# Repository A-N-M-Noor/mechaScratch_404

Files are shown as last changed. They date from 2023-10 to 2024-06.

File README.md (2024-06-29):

# wro_fe_2023 Engineering Documentation / PERA-METER / Team mechaScratch_404 / BANGLADESH
----
 <!-- ![mecha scratch main](https://github.com/A-N-M-Noor/mechaScratch_404/assets/136412241/82dec0fd-90a3-4080-8b9e-d6446caba096)   -->
mecha scratch main

### This repository is the collection of engineering materials pertaining to PERA-METER, a self-driving vehicle model developed by Team mechaScratch_404, participating in the 2023 WRO International Final (Future Engineers) from BANGLADESH.
----

## Team Members:
> A. N. M. Noor, email: noornoorrohan15@gmail.com

> Mahir Tajwar Chowdhury - email: tajwar185@gmail.com

----

 <!--  <img align="left" alt="NAUT" width="340" src="https://github.com/A-N-M-Noor/mechaScratch_404/assets/136412241/7f8c3910-39dc-47d4-9438-62cf6487e162">  -->

## Overview of our Repository
NAUT

 * `experiments` - codes that were used to do experiments.  
 * `models` - the 3D printable files used in our robot.
 * `getting started` - getting started guide.
 * `issues and solutions` - Issues we've faced and how we've worked around them.
 * `schematic` - contains the schematic of the electrical system of our robot.
 * `src` - contains the main code of our robot.
 * `video` - contains the video link of YouTube where our robot can be seen in action.
 * `t-photos` - contains one serious and one funny photo of our team.
 * `v-photos` - contains the photos of the robot from all required directions
 * `others` - other essential photos.
----
----
----


## Mechanical Design

We've made our robot totally from scratch. Most of the parts of our robot are 3D printed, starting from chassis, wheels, and so on.

### Mechanical Parts List
* Axial Bearing (8mm x 16mm x 5mm)
* Axial Flange Bearing (3mm x 8mm x 4mm)
* M3 bolt
* M3 nut
* M2 bolt
* M2 nut
* M3 Hex Spacer
* 3d Printed parts
* Zip ties

----

## Robot's Chassis



The chassis of our robot, primarily composed of 3D-printed parts, serves as the robust foundation for all hardware and electronic components. Custom-designed to accommodate our specific needs, each piece has been modeled to interlock seamlessly, providing a lightweight yet durable structure. The modular nature of the 3D-printed chassis allows for easy customization and scalability. It has been engineered to house the motors, electronics, and battery, ensuring proper heat dissipation and weight distribution for optimal performance. This approach not only allows for rapid prototyping and iterative design but also ensures that parts can be replaced or upgraded with minimal effort as the robot evolves. 
[All the 3D printable models and instructions can be found here](https://github.com/A-N-M-Noor/mechaScratch_404/tree/main/models).

----

## Electrical design of our robot.
bleh

In order to achieve the highest possible efficiency and reliability, we have spent several hundred hours researching and developing the parts. The following paragraphs provide detailed information about electrical systems design.

### Electronics Parts list

* Jetson Nano Developer Kit (4GB)
* Esp32 Development Board
* USB to TTL Serial Converter
* Micropack MWB-15 Pro FHD 2MP Stream Webcam
* 500 rpm 25GA 12V DC Gear Motor
* DS3235 Servo
* 5xHC-SR04 Ultrasonic Sensors
* TB6612FNG Motor Driver
* MPU6050
* 3.0 USB Type-C PD Power module
* XL6009 Buck Boost Module
* 3S LiPo battery input through XT60 Connector
* Mini Rocker Switch
* Push Button
* LED (3mm)
* Electrolytic Capacitor (1000μF)
* MINI MP1584EN DC-DC BUCK
* MINI DC-DC STEP DOWN POWER SUPPLY

 [Circuit diagrams and schematics can be found here](https://github.com/A-N-M-Noor/mechaScratch_404/tree/main/schematic).

----

## Mobility Management
* The front axle is being articulated by the Servo Motor.
* To control our Motor we have used a TB6612FNG motor driver.
* We used Ackerman steering as it is a vital steering geometry concept that enhances the handling and cornering performance of vehicles, making them safer and more efficient on the road. Ackerman steering, also known as Ackerman geometry or Ackerman principle, is a steering mechanism that is used in vehicles in order to enable proper turning of the wheels while maintaining optimal geometry and minimizing tire scrubbing during turns. It is commonly used in most modern vehicles, including cars, trucks, and other wheeled vehicles.
The fundamental idea behind Ackerman steering is that the inner and outer wheels of a vehicle must follow different turning radii during a turn, considering the varying angles of the front wheels. When a vehicle turns, the inner wheel needs to negotiate a tighter radius than the outer wheel to maintain a smooth turn without dragging or scuffing the tires. The Ackerman steering mechanism achieves this by using a steering linkage that connects the wheels. Typically, it consists of two tie rods connected to the steering arms on each wheel. The tie rods are connected to a central steering mechanism, such as a steering rack or a pitman arm, which is controlled by the driver. As the driver turns the steering wheel, the steering mechanism transfers the motion to the tie rods, causing the wheels to rotate accordingly. The geometry of the Ackerman steering mechanism ensures that the inner wheel turns at a sharper angle compared to the outer wheel, allowing both wheels to trace their respective turning radii accurately. By implementing Ackerman steering, vehicles can achieve better maneuverability, stability, and reduced tire wear during turns. It ensures that all wheels maintain proper contact with the road surface and minimizes the likelihood of skidding or slipping during turns.

* We also used a differential gearbox for the rear wheels. Although it uses a single DC motor, its primary purpose is to enable the wheels on a single axle to rotate at different speeds while receiving power from the engine and transmission. This crucial function allows for smooth and stable operation, particularly when the vehicle is turning. The differential works by distributing power from the input (usually the driveshaft) to the wheels. It ensures that both wheels receive power depending on the direction it's turning.

| Ackerman steering | Differential gearbox |
| --- | --- |
|NAUT |NAUT |

 ----
 ----
## Power and Sense Management
* The main camera is placed at the top of the robot facing slightly downwards. This downward-facing angle enhances the camera's ability to detect objects effectively, starting from close proximity and extending to objects situated further away.
* We've designed a sonar mount which is mounted at the front and the side of the robot where the front-left and front-right sonar sensors are mounted at an angle of 52.5 degrees. Based on our testing, this is the optimal angle for the sonars to detect walls ahead of time, giving the bot enough time to react.
* We're using a Jetson Nano to handle the image processing algorithms. The Jetson Nano uses a camera to detect towers and corner lines and sends the data to ESP32 via serial communication.
* A Buck-Boost modules were used for getting a constant output of 12V for the Motor
* Two buck module is used. One is for getting a constant 6V for the Servo, and the other one is for getting a constant 5V for the ESP32.
* A DC Quick Charge Adapter is used to power the Jetson.

### Custom hand made circuit board
| Top | Under | Power management |
| --- | --- | --- |
|NAUT |NAUT | NAUT |

----

NAUT

## Debugging
* We're using a 7-inch Pi display to debug problems regarding the Jetson Nano and Python programs.
* A buzzer is turned on for 200 milliseconds each time the robot detects a turn.
* The input button's GPIO pin is also being used to control an LED that shown the current state of the robot (ie: following object, lost object etc.)
----
----
## Program infrastructure and explanation of algorithm.
### Qualifying Round
#### Avoiding walls:
The program initiates with an initial throttle value of 1 (Full forward) and a steer value of 0 (No steering). Then it evaluates each sensor, checking whether its measured distance falls below its designated maximum distance threshold. If this condition is met, the sensor's value is remapped within a range specified by a minimum and maximum value, both of which are confined to the 0-1 range. This remapping process is inversely related to distance; the closer an object is, the higher the remapped value becomes.

For sensors positioned to the sides, this recalibrated value is then either added or subtracted from the existing steer value, effectively influencing the robot's lateral movement.

In the case of the front sensor, its remapped value is employed to diminish the throttle value, effectively slowing the robot down as objects come closer. Additionally, it amplifies the current steer value, causing the robot to respond more rapidly and make sharper turns when objects are detected in close proximity.

sonarWalls drawio

This comprehensive sensor-driven control scheme ensures that the robot can effectively navigate and respond to its environment, making it capable of avoiding obstacles and adjusting its course as needed.

#### Lap count:
The Jetson Nano constantly looks for the corner lines using the camera. If the first line is blue, then the robot is going counter-clockwise, and if the first line is orange, then the robot is going clockwise. After determining the direction, then the program looks for the second line. Whenever it sees a line matching the color of the second line, it sends the data to the ESP32 and increases the turn count by one. To achieve the goal of completing three laps, the robot must complete 12 turns in total.
Therefore, when the turn count reaches the value of 12, the program triggers the robot to operate under normal conditions for a predetermined duration. After that, the robot comes to a halt, having completed three laps.

The robot harnesses the processing power of both cores of the ESP32 microcontroller by using FreeRTOS, a real-time operating system. The primary core handles all logical operations and calculations, ensuring the swift execution of tasks. Simultaneously, a separate core is dedicated to acquiring sensor data, allowing for rapid data retrieval. This dual-core configuration enables the robot to perform calculations and make decisions with remarkable speed and efficiency.

### Obstacle Round
At present, the robot uses OpenCV for detecting red and green towers. The Jetson Nano detects the colors of these towers, and by utilizing the on-screen width value of the detected towers in pixels, the robot can estimate the distance to any visible tower. This estimation is based on an inverse proportional relationship, expressed by the equation:

    distance = k/width

METRIC
METRIC
<br>
The value of ‘k’ was determined by plotting real-life data from
experiments on a graph. In our case, the value of ‘k’ is 2141. Using this value in the equation roughly matches the real-life data.

----
----

#### Avoiding walls:
This is done the same way as in the [qualifying round](#avoiding-walls).

#### Avoiding towers:
After obtaining the initial steer and throttle values from the sonar sensors, the program proceeds to adjust these values based on the presence of red and green towers in the environment.

The program systematically evaluates all visible towers and selects the one closest to the robot. Then it follows the robot up to a certain distance and then starts to avoid the tower based on the color. For this, it examines two key factors: the distance to the target tower and its horizontal position on the screen.

* **Distance Factor:** A numeric value between 0 and 1 is generated, and this value is directly proportional to the tower's proximity to the robot. The closer the tower, the larger this value becomes.

* **Horizontal Position Factor:** Another value ranging from 0 to 1 is determined based on the tower's horizontal position on the screen. For red towers, the program aims to make right turns, so a higher value is assigned when the tower is on the right side of the screen (influencing steering significantly), and the value decreases as the tower moves towards the left side. Conversely, for green towers, the same principle applies but with reversed sides.

These two calculated values are then multiplied together, yielding a new value also ranging from 0 to 1. This new value is added to or subtracted from the existing steer value. This dynamic adjustment based on tower presence and location allows the robot to navigate and react to the positions of red and green towers, facilitating precise and adaptable movement.

objectDetec drawio

Right after the robot passes a tower, it steers a little bit towards the opposite of the way it was steering in order to pass that tower. For example, if the robot passes a red tower, which means it has been steering towards the right side, the robot will steer towards the left for a brief moment. This ensures that the robot will notice the next object without issues.

As the robot keeps track of the blue or yellow lines placed at the corners of the track, it understands when to take a turn. Therefore, the robot takes a small turn whenever it notices a new line using its camera. It stops turning immediately when it sees a tower.

#### Avoiding collisions:
To address the possibility of collisions with walls or towers after modifying the steer and throttle values using the tower detection algorithm, the program implements continuous monitoring of distance values. If any of these values fall below a specified threshold, the program overrides the modifications made by the tower-avoidance algorithm and reverts to actions based on the distance values alone.

Additionally, if any object, such as a wall or tower, approaches closer to the robot than a predefined distance threshold, the program initiates a brief backward movement. During this backward motion, the program also adjusts the steer value based on the color of the target tower. For instance, if the robot detects a red tower, it may steer left while moving backward, and for a green tower, it may steer right. This dynamic response mechanism ensures that the robot takes evasive action to avoid collisions while considering the type and location of the detected objects.

collsn drawio

#### Lap count:
This is done the same way as in the [qualifying round](#lap-count).

#### U-turn:
The program keeps the history of towers it has encountered in its way. It stores them in a stack-like order. So, after the 8th turn, The robot starts looking for colored towers. There are a few possible scenarios:
* The robot detects a tower at the beginning or the middle of the section. Then that tower is the last tower.
  - If it's red, do a U-turn.
  - If it's green, disable u-turn.
* The robot detects a tower at the end of the section. Then the last object saved in the history stack is the final tower.
  - If it's red, wait until the robot gets to the middle of the section, and do a U-turn
  - If it's green, disable U-turn

uTurn drawio

After the robot makes a U-turn, it sends a flag to the Jetson to reset the turn count and flip the track direction.

Once again, the ESP32's primary core handles the calculations and decision-making processes, while the secondary core is responsible for collecting data from the distance sensors and the Jetson Nano. This configuration enables the robot to react quickly and avoid collisions with walls or obstacles.

----
----


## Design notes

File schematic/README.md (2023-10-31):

# Circuitry
### Circuit Schematic:
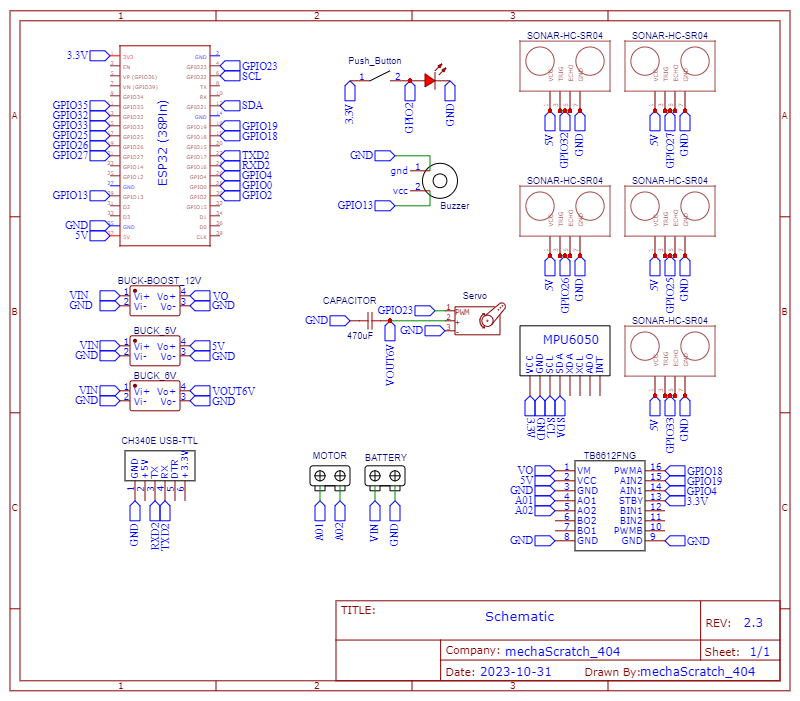
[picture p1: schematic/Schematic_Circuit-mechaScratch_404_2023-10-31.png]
Schematic


### ESP32 Pinout:
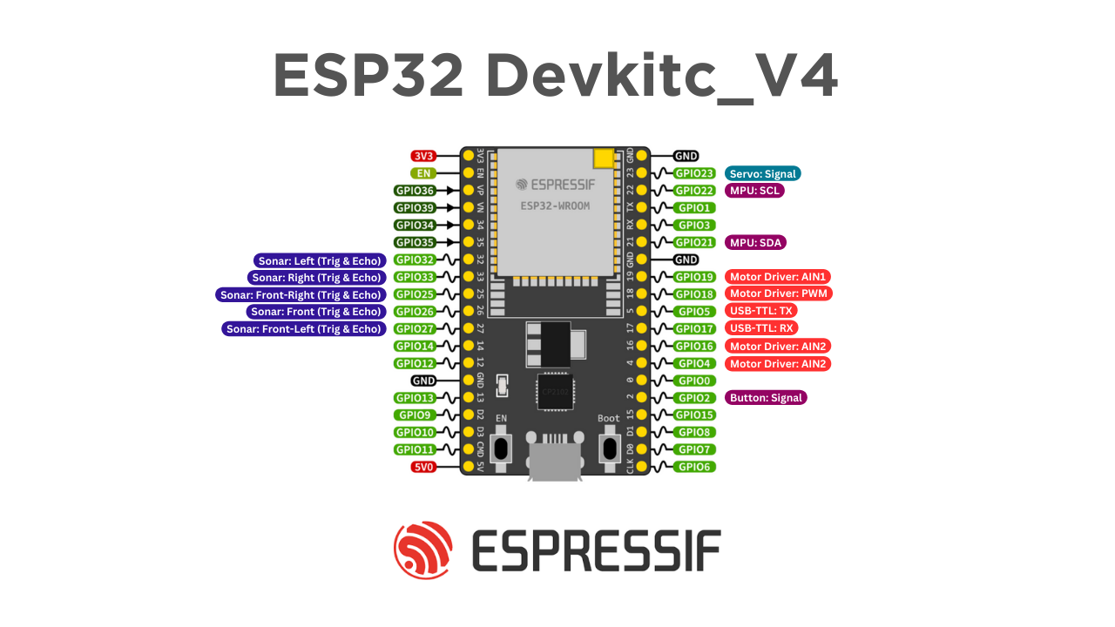
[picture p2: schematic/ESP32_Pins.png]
Schematic


* Only one GPIO pin is used per sonar sensor.
* One GPIO pin is used to take input from a button and also to control an indicator LED.
* A buck module is used for powering up the servo motor, which is set to 6V.
* A buck module is used for powering up the ESP32.
* A buck-boost module is used to constantly supply the motors with 12V.
* A buzzer is used as an indicator.
* A USB-TTL converter is used to communicate between the Jetson and the ESP32.

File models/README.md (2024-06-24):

# 3D printable files
This directory contains all the 3D files for 3D printing the robot. All the models are optimized to print without support, and with a low amount of infill to ensure a quick print.

## Instruction
The names of the STL files indicate the number of printed parts needed and the strength requirement.

Example file name:

`FrontWheel (2x) (Mid).stl`

Here, `(2x)` indicates this model needs to be printed twice. And `(Mid)` indicates the strength required for the printed part.

* Weak:
  - Infill: Low
  - Walls/Perimeters: 3
  - Top. Bottom layers: 3
* Mid:
  - Infill: High
  - Walls/Perimeters: 5
  - Top. Bottom layers: 3
* Strong:
  - Infill: High
  - Walls/Perimeters: 5
  - Top. Bottom layers: 5

## Assembly steps

| 1. Assemble the gearbox: | 2. Assemble the wheel: |
| --- | --- |
| NAUT | NAUT

| 3. Assemble the steering mechanism: | 4. Assemble the base plate: |
| --- | --- |
|  NAUT| NAUT |

| 5. Assemble the top plate: | 6. Assemble the final top plate: |
| --- | --- |
|NAUT | NAUT |

 > [!NOTE]
 > Use zip ties to secure the camera to tha camera base

----
----

### Final assembly should look like this (Excluding fasteners):
NAUT
NAUT
NAUT

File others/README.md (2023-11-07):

# Other important photos/videos
* (Deprecated) `Steering Mechanism`: This is a video demonstrating the steering mechanism in action. You can watch this video on YouTube by following [this link](https://youtu.be/_olSEMrKiMA). This video offers a visual representation of the steering mechanism's operation, providing a clearer understanding of how it functions.

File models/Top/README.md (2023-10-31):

# Top part

Final assembly should look like this:


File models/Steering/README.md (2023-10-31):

# Steering Mechanism

Final assembly should look like this:


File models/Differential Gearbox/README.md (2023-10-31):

# Differential Gearbox

Final assembly should look like this:


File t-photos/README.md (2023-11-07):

# Team Photos

| Serious Photo | Funny Photo |
| --- | --- |
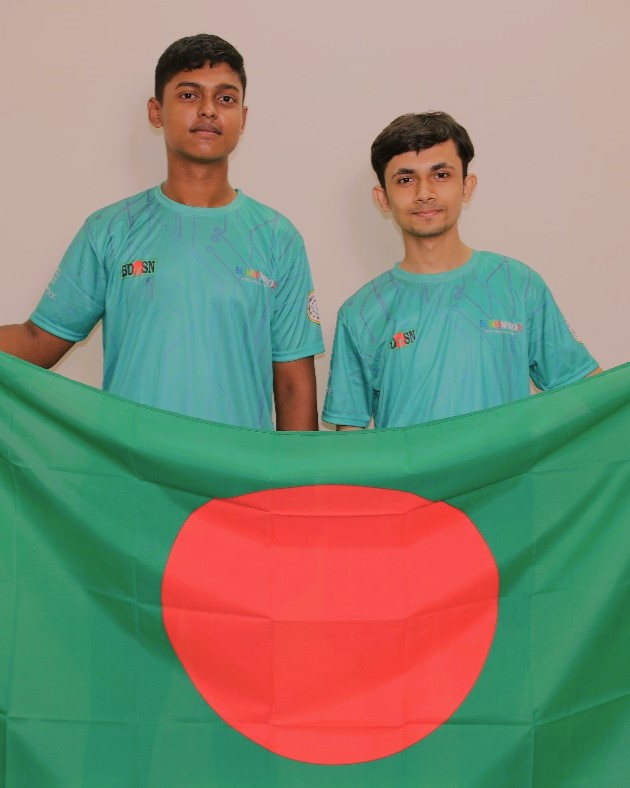
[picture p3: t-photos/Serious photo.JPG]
serious
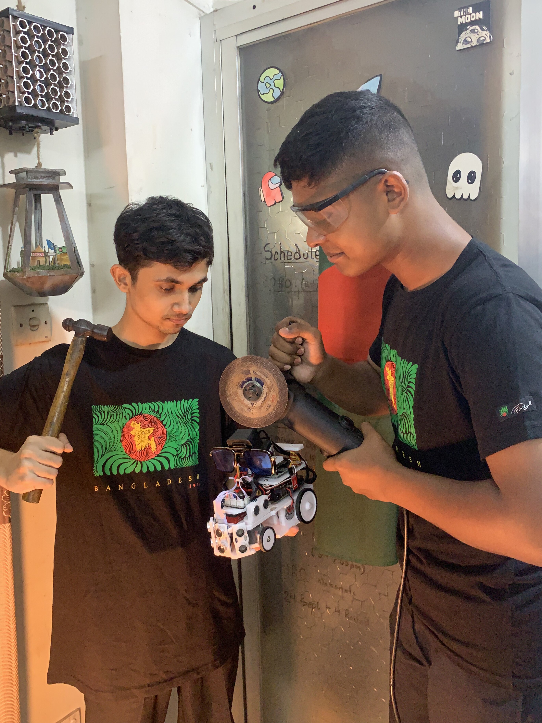
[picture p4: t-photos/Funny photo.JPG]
funny
|  |  |

| Working Photo                       |
| ----------------------------------- |
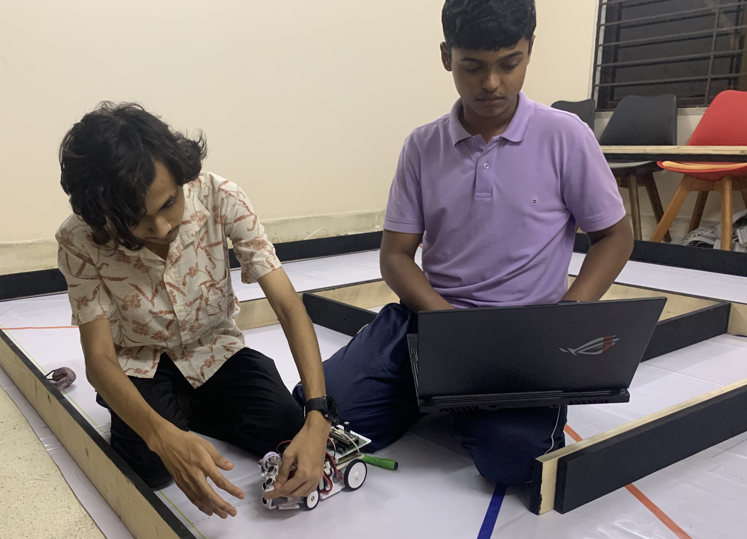
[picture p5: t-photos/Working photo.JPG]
working
|  |

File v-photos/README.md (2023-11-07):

# This folder contains photos of the robot from all required directions.

| Front | Back |
| --- | --- |
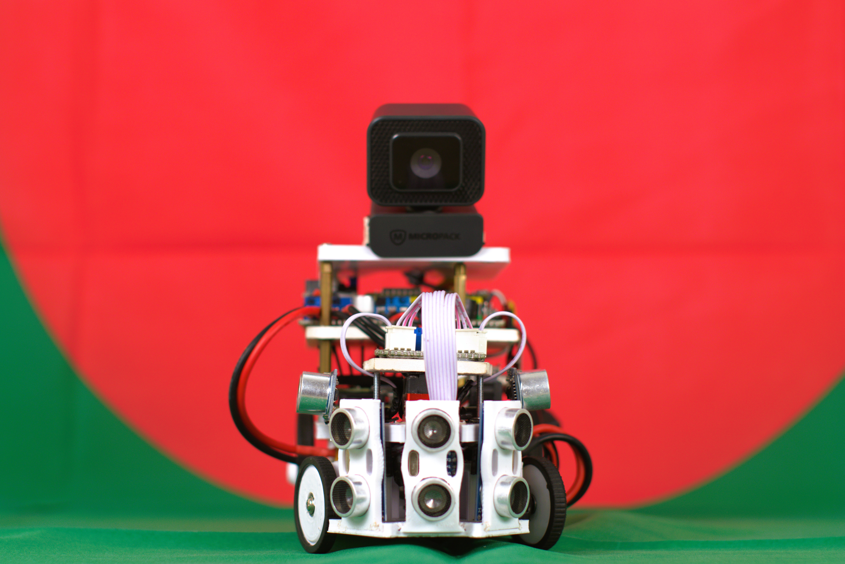
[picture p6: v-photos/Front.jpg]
front
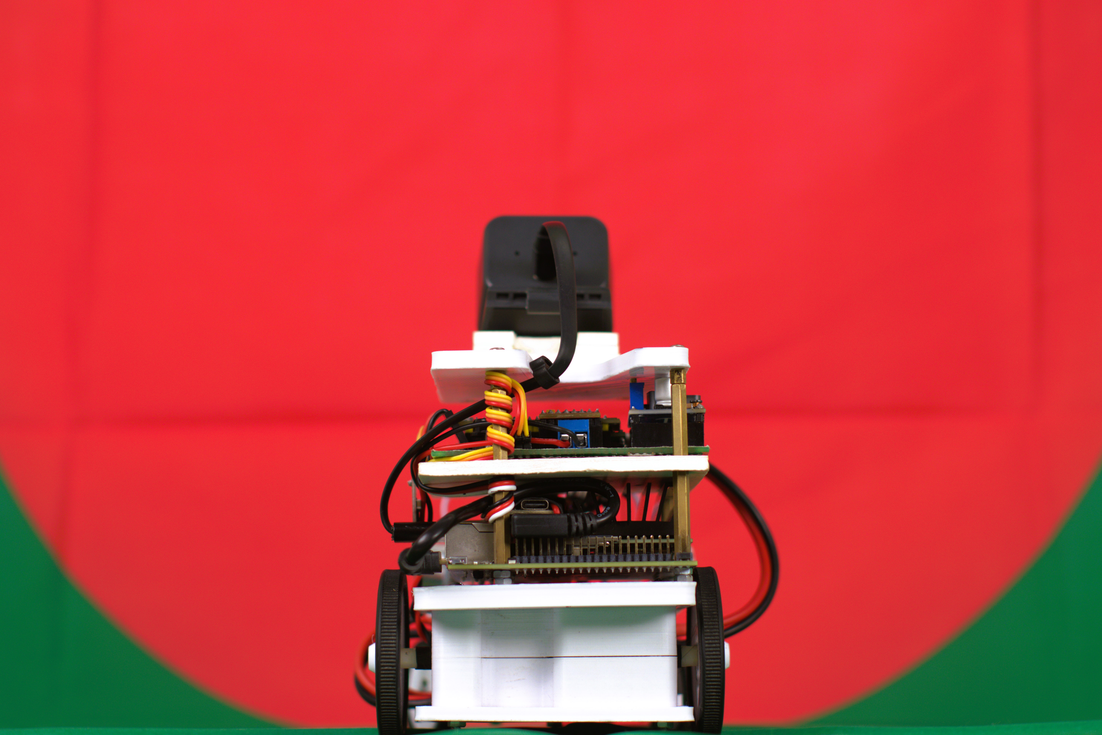
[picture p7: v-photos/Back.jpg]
back
|  |  |

| Top | Bottom |
| --- | --- |
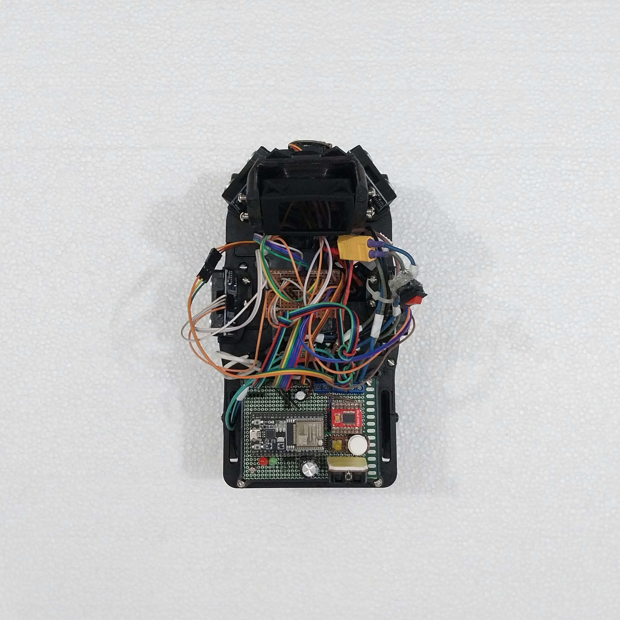
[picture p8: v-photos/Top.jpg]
top
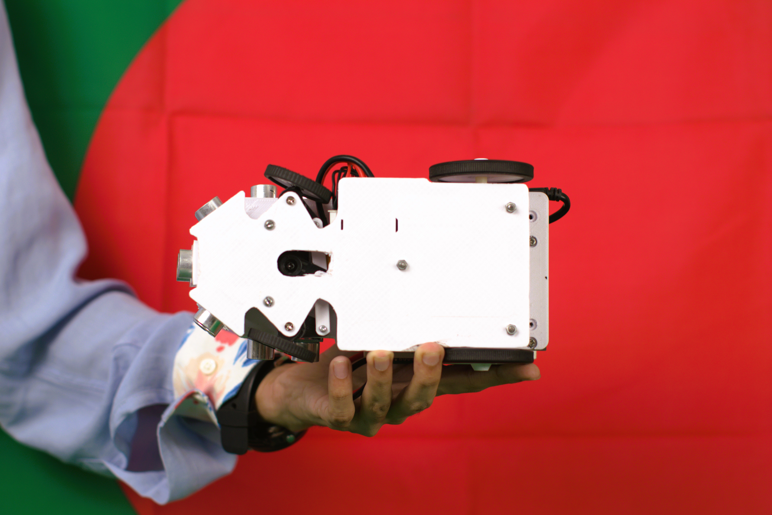
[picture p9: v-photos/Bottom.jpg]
bottom
|  |  |

| Left | Right |
| --- | --- |
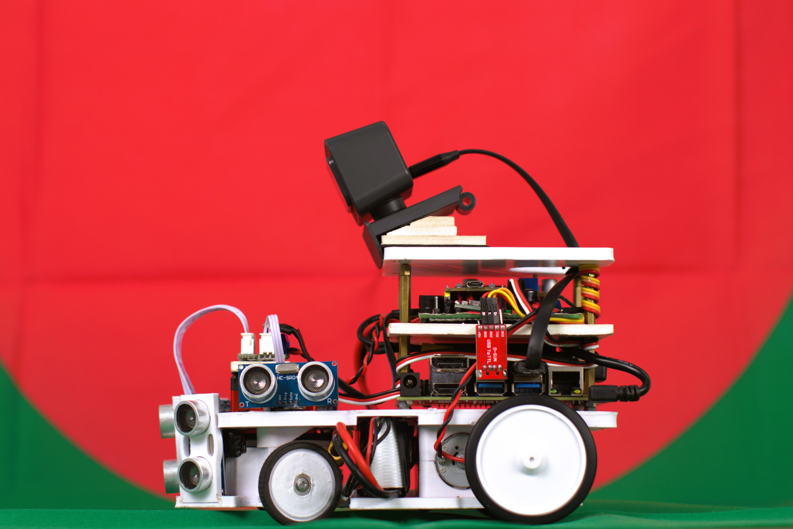
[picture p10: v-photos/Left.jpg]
left
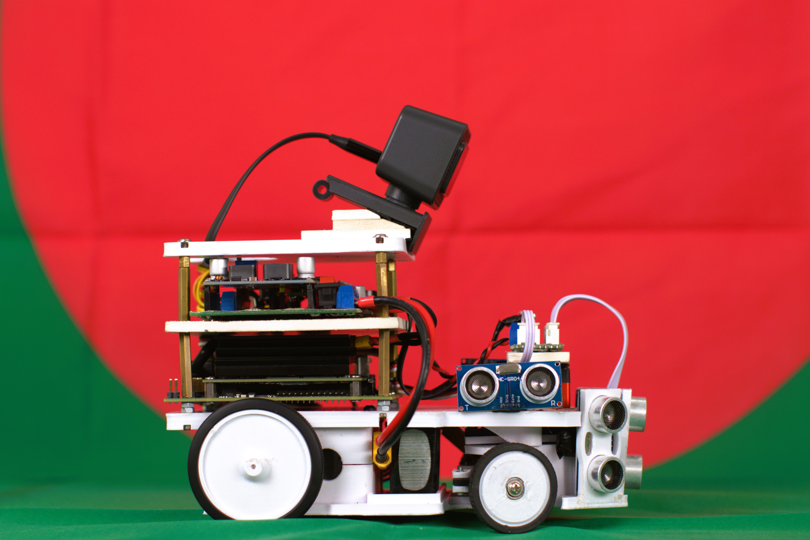
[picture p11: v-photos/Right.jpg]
right
|  |  |

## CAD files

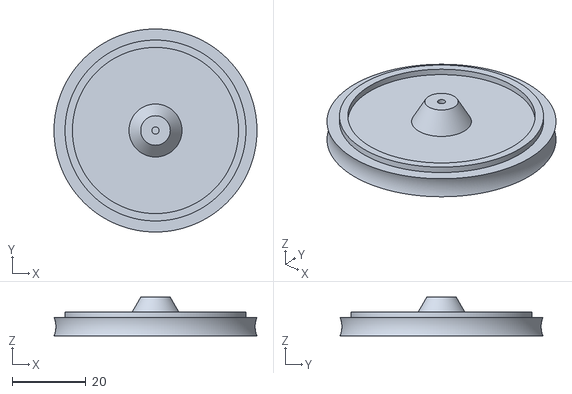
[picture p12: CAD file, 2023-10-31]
models/Differential Gearbox/BackWheel (2x) (Mid).stl
55.0 x 55.0 x 10.5

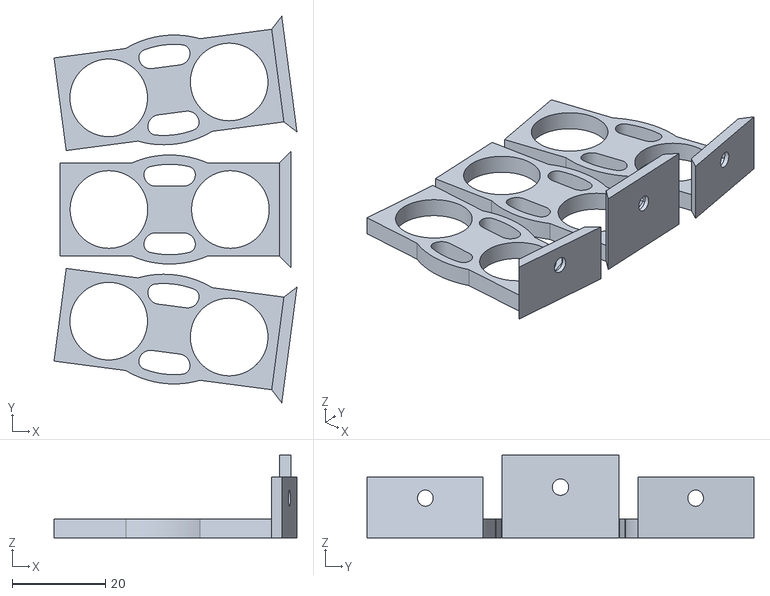
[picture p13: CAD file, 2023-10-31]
models/SonarHolders (1x) (Weak).stl
52.0 x 82.8 x 17.7

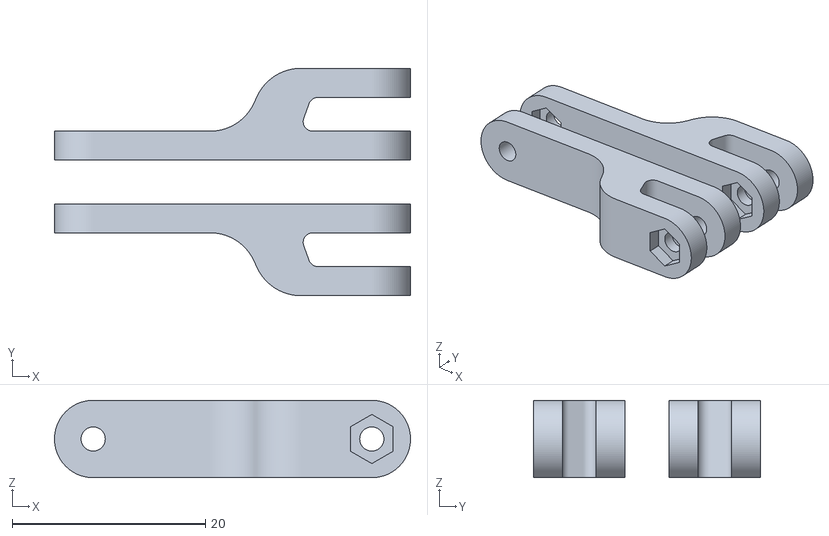
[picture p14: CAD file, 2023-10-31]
models/Steering/SteerLinks (2x) (Strong).stl
36.8 x 23.5 x 8.00

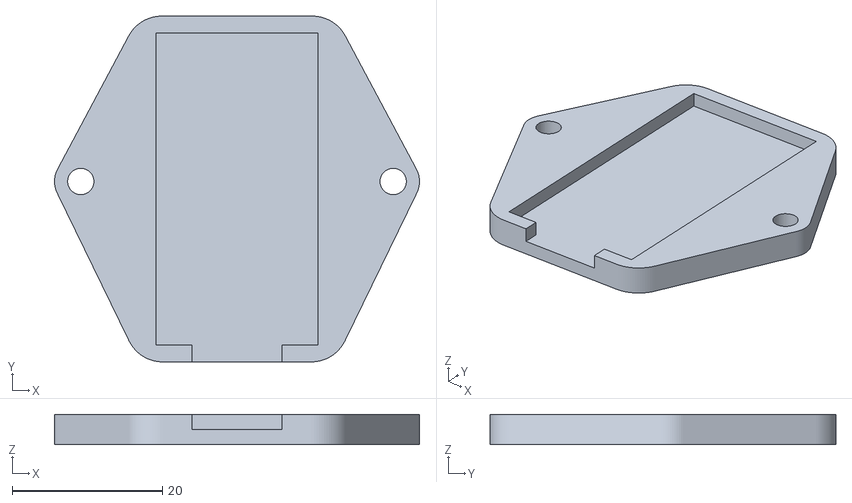
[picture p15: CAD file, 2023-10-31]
models/Top/SonarCircuitHolder (1x) (Weak).stl
48.6 x 46.0 x 4.00

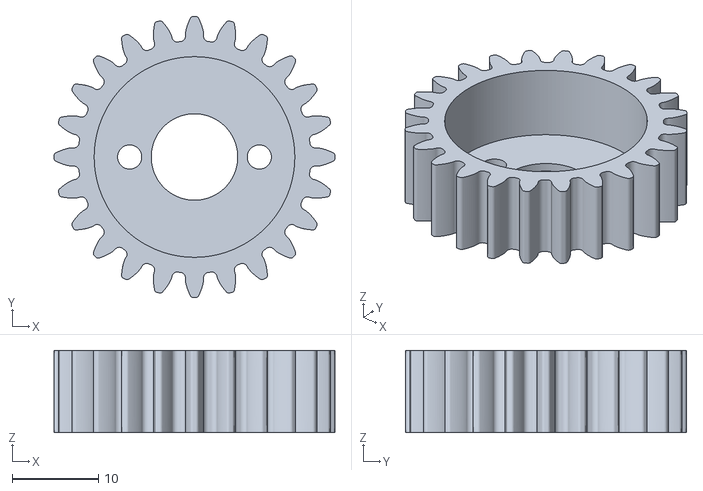
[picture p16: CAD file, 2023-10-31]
models/Differential Gearbox/GearDiff (2x) (Strong).stl
32.5 x 32.5 x 9.50

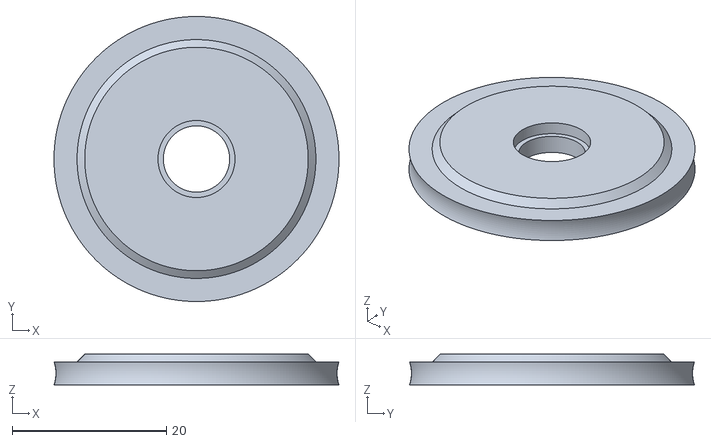
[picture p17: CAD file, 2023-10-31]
models/Steering/FrontWheel (2x) (Mid).stl
37.0 x 37.0 x 4.00

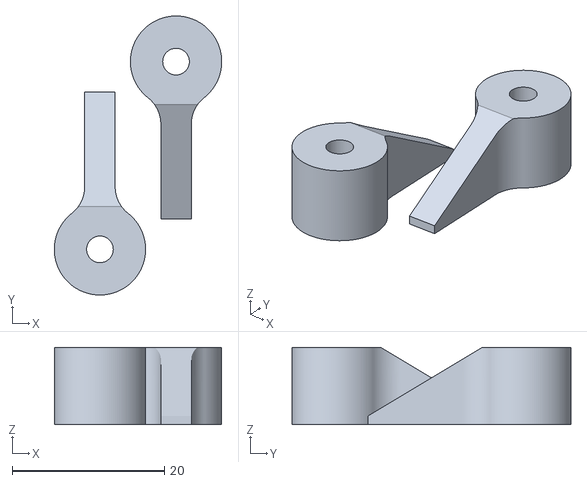
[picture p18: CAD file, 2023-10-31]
models/SupportColumnTop (1x) (Mid).stl
22.0 x 36.7 x 10.2

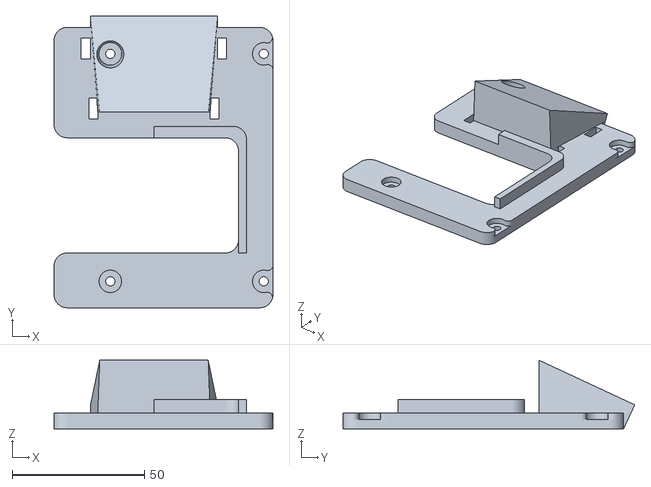
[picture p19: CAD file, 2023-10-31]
models/Top/CamBase (1x) (Weak).stl
82.8 x 110.2 x 26.0

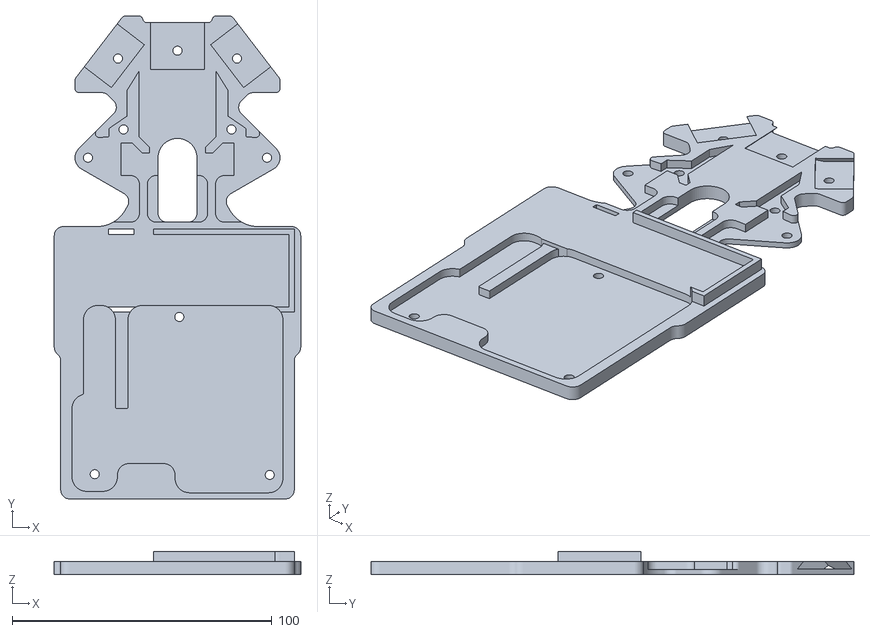
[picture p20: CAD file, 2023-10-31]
models/Base_Bottom (1x) (Weak).stl
95.0 x 186.1 x 9.00

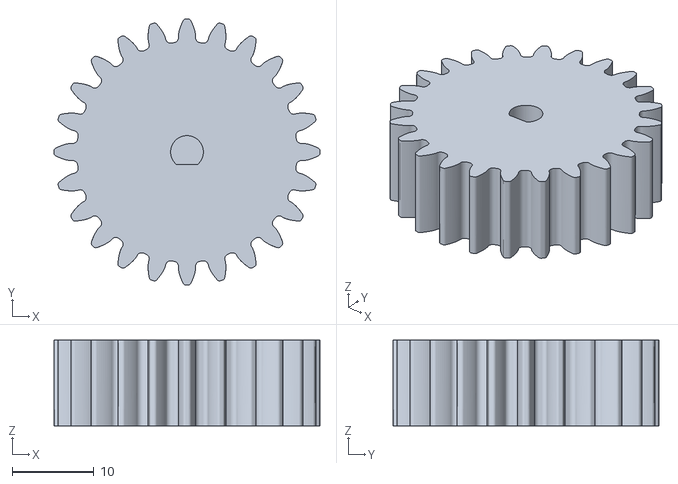
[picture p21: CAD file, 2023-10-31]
models/Differential Gearbox/GearMot (2x) (Strong).stl
32.5 x 32.5 x 10.5

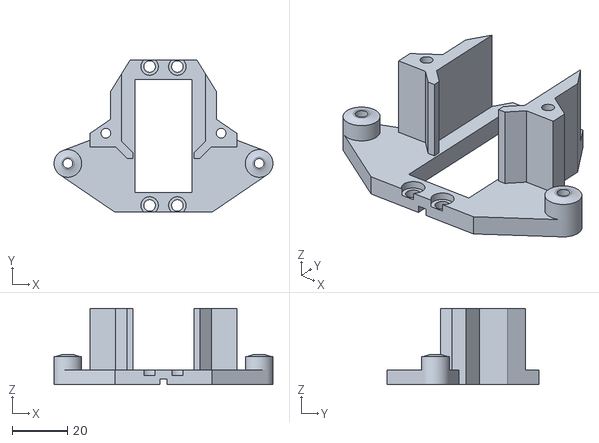
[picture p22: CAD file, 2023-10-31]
models/Steering/SteerTop (1x) (Mid).stl
79.0 x 55.0 x 27.5

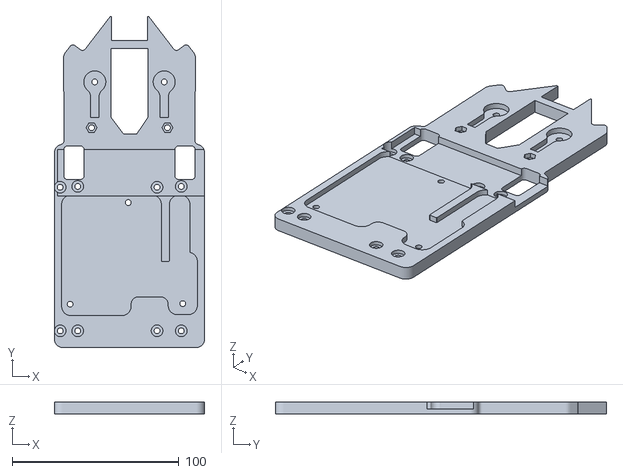
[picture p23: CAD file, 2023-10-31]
models/Top/TopPlate (1x) (Weak).stl
90.0 x 198.3 x 7.00

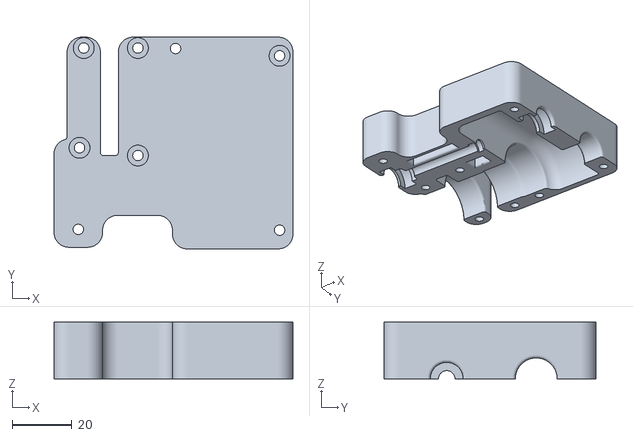
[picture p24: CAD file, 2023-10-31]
models/Differential Gearbox/GearBox_Top (1x) (Weak).stl
80.1 x 71.0 x 19.0

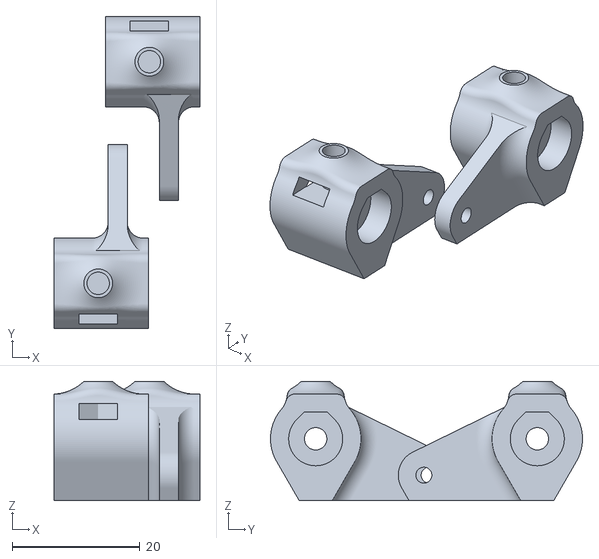
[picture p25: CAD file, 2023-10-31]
models/Steering/Steers (2x) (Strong).stl
22.8 x 48.8 x 18.7

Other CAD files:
models/Top/CircuitHolder (1x) (Weak).stl
models/Differential Gearbox/GearBox_Bottom (1x) (Weak).stl
models/Top/TopSonarBase (1x) (Weak).stl
models/Top/TopSonarMount (1x) (Weak).stl

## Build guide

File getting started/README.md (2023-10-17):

# Getting Started
We are using a **NVIDIA Jetson Nano Developer Kit** for object detection, and an **ESP32 Microcontroller** for the sensors and for handling the controls. So before anything, you must set up your Jetson Nano and ESP32.

## Setting up the Jetson Nano
Detailed instructions can be found on [NVIDIA's official website](https://developer.nvidia.com/embedded/learn/get-started-jetson-nano-devkit)



The **NVIDIA Jetson Nano Developer Kit** is a small single-board computer. You'll need to flash an operating system (usually Ubuntu) in a micro SD card and insert it into the Jetson Nano. So, you'll need - 
* A micro SD card (32GB or 64GB)
* Micro-USB supply/adapter (Should be at least 10W)
* USB keyboard and mouse
* Computer display with HDMI cable (You can use a VGA Cable too, but you'll need an HDMI to VGA Converter)

### Flashing an SD card
To prepare your microSD card, you’ll need a computer with an Internet connection and the ability to read and write SD cards via a built-in SD card slot or adapter.
1. Download the [Jetson Nano Developer Kit SD Card Image](https://developer.nvidia.com/jetson-nano-sd-card-image)
2. Format your SD card
3. Install an image writer application. We've used [Etcher](https://etcher.balena.io/)
4. Click **Select Image** and select the image file you've downloaded just now.



5. Insert your SD card and select the SD drive from **Select Drive**, then click **Flash!**



6. After it's done flashing the image, you can eject your SD card from your device.

### Setup and First Boot
Insert the SD card in the SD slot of your jetpack and power it up. For the first boot, you'll need to use a monitor, keyboard and mouse. Also, connect a wifi dongle to the jetpack if you don't have the network card installed with it.



A green LED next to the Micro-USB connector will light as soon as the developer kit powers on. When you boot the first time, the developer kit will take you through some initial setup, including:
* Review and accept NVIDIA Jetson software EULA
* Select system language, keyboard layout, and time zone
* Create username, password, and computer name
* Select APP partition size—it is recommended to use the max size suggested

Now you'll be able to use the Jetson Nano as you would use any other Ubuntu PC. But we want to use it without any monitor or keyboard and mouse attached. So we'll use a Remote desktop application (VNC for example).

### Setting up VNC
Now, Jetson comes with "Desktop Sharing" installed. But it fails due to a bug. To solve this issue -
1. Install "nano", which is a command used to edit files from the terminal. To install "nano", open up a terminal and write
```
sudo apt install nano
```
2. First, we will edit the _org.gnome.Vino_ schema, as it has a missing parameter called enabled. Open the schema:
```
sudo nano /usr/share/glib-2.0/schemas/org.gnome.Vino.gschema.xml
```
3. Add the missing key (any location will do):
```XML
<key name='enabled' type='b'>
   <summary>Enable remote access to the desktop</summary>
   <description>
   If true, allows remote access to the desktop via the RFB
   protocol. Users on remote machines may then connect to the
   desktop using a VNC viewer.
   </description>
   <default>false</default>
</key>
```
4. Compile the new Gnome schema configuration:
```
sudo glib-compile-schemas /usr/share/glib-2.0/schemas
```
5. Update the Desktop Sharing settings. Your application should work now. Launch it from your Jetson Nano desktop and change the settings as it suits you.
6. Setup the VNC server to autostart
   - Open the Startup Application Preferences panel
   - Add your VNC (Vino) entry: Add a name ('Vino'), a description (any text which makes sense to you) and the command: ```/usr/lib/vino/vino-server```. Close the app.
7. Disable encryption for the VNC server
   ```
   gsettings set org.gnome.Vino require-encryption false
   gsettings set org.gnome.Vino prompt-enabled false
   ```
8. Reboot

After reboot, you can use any [VNCViewer](https://www.realvnc.com/en/connect/download/viewer/) from your laptop to connect to the shared screen.

### Python and Python Modules
Jetson comes with Python 2.7 and Python 3. For this project, we'll use Python3. But we'll need to install a few libraries.
* OpenCV
* Numpy
* pySerial

First, update and upgrade your package manager:
```
sudo apt-get update
sudo apt-get upgrade
```

Install 'pip' aka python package manager, and build-essentials:
```
sudo apt install -y python3-pip
sudo apt install build-essential libssl-dev libffi-dev python3-dev
```

Now install OpenCV:
```
sudo apt install python3-opencv
```
Install numpy:
```
pip3 install numpy
```
Install pyserial:
```
pip3 install pyserial
```

## Setting up the ESP32



ESP32 is a pretty powerful microcontroller. It is a dual-core 32-bit MCU, which means we can run two loops in parallel which would make our robot a lot faster. To keep it simple, we'll use the Arduino IDE to compile codes for the ESP32 Microcontroller.

### Installation
* Download and install the [Arduino IDE](https://www.arduino.cc/en/software). As of now, the latest version is `2.2.1`, but it lags on a low-end device. So install the Legacy IDE (`1.8x`) for now.



* In your Arduino IDE, go to File > Preferences, and enter the following into the "Additional Board Manager URLs" field, and click OK: 
```
https://raw.githubusercontent.com/espressif/arduino-esp32/gh-pages/package_esp32_index.json
```


* Open the Arduino Boards Manager: `Tools > Board > Boards Manager...` and search for **ESP32**. Find the one named "ESP32 by Espressif Systems" and click on "Install".


* Install the necessary libraries:
   - Go to `Sketch > Include Libraries > Manage Libraries...`

   - Find and install **"ESP32Servo"** by _"Kevin Harrington"_ and **"NewPing"** by _"Tim Eckel"_.



* Select your Board in the `Tools > Board` menu. Select the one named "ESP32 Dev Module". This one works for almost every ESP32 board.


* When you need to upload a code, select the port from `Tools > Port` and hit upload.



Now, depending on what ESP32 board you're using, you might not be able to upload the code just yet (There are some knock-off versions available in the market). Install the [CP2102 Driver](https://www.silabs.com/documents/public/software/CP210x_Windows_Drivers.zip) and try again. It should work now.
_______

Source:
* [https://developer.nvidia.com/embedded/learn/get-started-jetson-nano-devkit](https://developer.nvidia.com/embedded/learn/get-started-jetson-nano-devkit)
* [https://raspberry-valley.azurewebsites.net/NVIDIA-Jetson-Nano/](https://raspberry-valley.azurewebsites.net/NVIDIA-Jetson-Nano/)

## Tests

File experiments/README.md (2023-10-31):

# Experiments done to check each feature separately
### ESP32
1. `ExampleMotor`:
   - Purpose: This code was designed to validate the motor control system.
   - Procedure: It receives throttle values ranging from -1 to 1 via the serial monitor and translates them into motor actions, including reverse movement for negative values.
   
2. `ExampleSteer`:
   - Purpose: This experiment focused on testing the steering servo's performance.
   - Procedure: The code sweeps the steering servo within a predefined steering angle range. The angle can be adjusted using the variable named **steerAngle**.

3. `MPU_and_MultiLoop`:
   - Purpose: This experiment aimed to evaluate the MPU-6050 module's gyro values and explore the functionality of the ESP32 microcontroller's free RTOS, utilizing both of its cores.
   - Procedure: The code continuously reads and prints gyro values from the MPU-6050 module at specified intervals, showcasing the utilization of the microcontroller's dual-core capabilities.

4. `SerialSteer`:
   - Purpose: This code allows fine-tuning the servo angles to calibrate the steering.
   - Procedure: With the steering assembled, upload the code. Then remove the servo head from the servo, and power up the microcontroller. Open up the serial monitor and set the angle to 90. Then connect the servo head and adjust the steering angle.

5. `Sonar5x`:
   - Purpose: This experiment focused on the ultrasonic distance sensors.
   - Procedure: The code retrieves distance values from all five sonar sensors and displays them in the serial monitor.
____

### Jetson Nano

1. `HSV_RangeFinder.py`:
   - Purpose: This code allows to easily calibrate the color ranges for the purpose of detecting the objects and lines.
   - Procedure:
     - Run the code, place an object/line in front of the camera. Four windows should open-up.
      

      - Now click on the object with your mouse within the window named "original". It should create a basic mask for you. 
      

      - Use the sliders to fine tune the mask.
      

      - Press 's' on your keyboard to print the HSV range in the terminal. It will also ask you for a name. Give the color a name in the terminal, and the program will save the color range in a JSON file in the directory: 'Data/Colors.json'.

2. `(deprecated) camThreading.py`:
   - Purpose: This code uses two cameras (Webcam and pi camera) simultaneously using threading

      > [!NOTE]
      > We're no longer using both cameras. But this is how it can be done using multithreading.
____
These experiments were conducted separately to ensure that each component and feature operates as expected in isolation. Such a systematic approach to testing ensures that the various elements of the robot's system are thoroughly examined and verified before integration into the final design.

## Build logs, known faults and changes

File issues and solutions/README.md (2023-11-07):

# Issues we've faced and how we've worked around them

## Color Detection
Detecting colors using RGB color space gives unreliable outcomes. The reason is, that a bright red color and a dark red color have completely different values in RGB color space. But if HSV color space is used instead, these color values become much more reliable.

The HSV color code, also known as HSB (Hue, Saturation, Brightness), is a color model used to describe and represent colors in terms of three fundamental attributes: hue, saturation, and brightness. It is often used in computer graphics, image processing, and design applications. Here's a brief explanation of each component:

HSV

* **Hue (H):** Hue refers to the dominant color in a particular shade. It is measured in degrees on a color wheel, typically ranging from 0 to 360 degrees. In this representation, 0° corresponds to red, 120° to green, and 240° to blue, with the other colors filling the spectrum in between.

  _However, in OpenCV, the range for hue is from 0 to 180._

* **Saturation (S):** Saturation indicates the intensity or purity of the color. It is usually represented as a percentage and ranges from 0% (completely unsaturated, grayscale) to 100% (fully saturated, vibrant color). Higher values result in more vivid colors, while lower values approach grayscale.

  _However, in OpenCV, the range for saturation is from 0 to 255._

* **Brightness (V or B):** Brightness represents the lightness or darkness of a color. It is also typically expressed as a percentage, with 0% being completely black and 100% being the full brightness of the color at its specified hue and saturation.

  _However, in OpenCV, the range for brightness is from 0 to 255._

By combining these three components (H, S, and V), you can specify a wide range of colors. And HSV color space somewhat represents the way humans perceive colors. This makes the HSV color model a more intuitive and user-friendly way to describe and select colors compared to other color models like RGB or CMYK, which are based on the additive or subtractive properties of light.

## Serial communication
The jetson nano and esp32 use serial communication to exchange data. But the sent and received data was turning into garbage values on both the jetson and esp32 side. To overcome the issue of data corruption during serial communication between the Jetson Nano and ESP32, a revised approach was adopted. Instead of sending all the data in a single block, it was segmented into key-value pairs. In this setup, the key ranges from 0 to 49, and the value ranges from 50 to 250. Since both key and value fall within the 0-255 range, they can be transmitted as 8-bit codes.

The communication process unfolds as follows:

1. The ESP32 initiates the data request from the Jetson.
2. The Jetson, in response, sends the data in a specific sequence, starting with a key and followed by a corresponding value.
3. Upon receiving a key, the ESP32 anticipates the next value to follow. For instance, if the ESP32 receives the key '6,' it interprets this as an identifier for the upcoming value.
4. However, to determine the accurate value, the ESP32 subtracts 50 from the received value, as the values commence from 50.

This data exchange approach ensures reliable communication between the Jetson Nano and ESP32, allowing for the accurate transmission and interpretation of information without the risk of data corruption.

Here's the list of key-value pairs we've used in our program:
* 5 - Object type
* 6 - Object position (x position)
* 7 - Object distance
* 8 - Turn count
* 10 - Track direction

## The robot randomly bumps into objects



The robot encounters occasional instances where it unintentionally collides with walls or some towers. To mitigate this issue, a collision avoidance algorithm has been implemented. When the robot detects objects in close proximity, it responds by executing a brief backward movement, effectively reversing its direction for a short distance. Following this reverse action, the robot proceeds with its regular course of operation, thereby minimizing the impact of accidental collisions and promoting smoother navigation.

----
----
----
----

## Issues with the back camera
In the initial plan, a dedicated camera (Raspberry pi camera v2.1) was positioned at the back of the robot, facing downward, with the sole purpose of counting the corner lines. However, there was an issue with the feed from the Pi-camera, which exhibited a persistent purple hue. To address this problem, adjustments were made, involving white balancing and color correction to rectify the color distortion.

As the robot's speed increased, particularly during the open round, the downward-facing Pi-camera struggled to keep pace and occasionally missed detecting some of the lines. In response to these challenges, a decision was made to streamline the setup by utilizing a single camera for both tower and line detection, simplifying the hardware configuration and enhancing overall efficiency.

## After passing an object, the robot misses the next one
When the robot encounters a tower, particularly in the corners, it may intermittently lose sight of the next tower, causing it to deviate from its intended path. This deviation can result in the robot's movement resembling the following pattern:

Miss
  
To address the challenge of losing sight of the next tower after passing one, the robot has implemented two key strategies:

1. **Momentary Steering Correction:** Immediately after passing an object, the robot briefly steers in the opposite direction, counteracting the previous turn. If the last detected object was red, it steers to the left, and if it was green, it steers to the right, straightening its direction a bit. This corrective action helps the robot align itself and regain its intended path.

2. **Corner Detection and Adaptive Turning:** As soon as the robot identifies a corner in the track, it executes a brief turn towards the direction of the track. However, it promptly ceases this turning action upon detecting an object. This approach allows the robot to effectively navigate corners while remaining responsive to obstacles.

This way, the robot manages to handle the corners better.

Find

These two strategies work in tandem to enhance the robot's ability to maintain a consistent and accurate course, especially when negotiating corners and navigating between towers.

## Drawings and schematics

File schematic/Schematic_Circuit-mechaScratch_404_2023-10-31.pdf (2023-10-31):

A | A

1

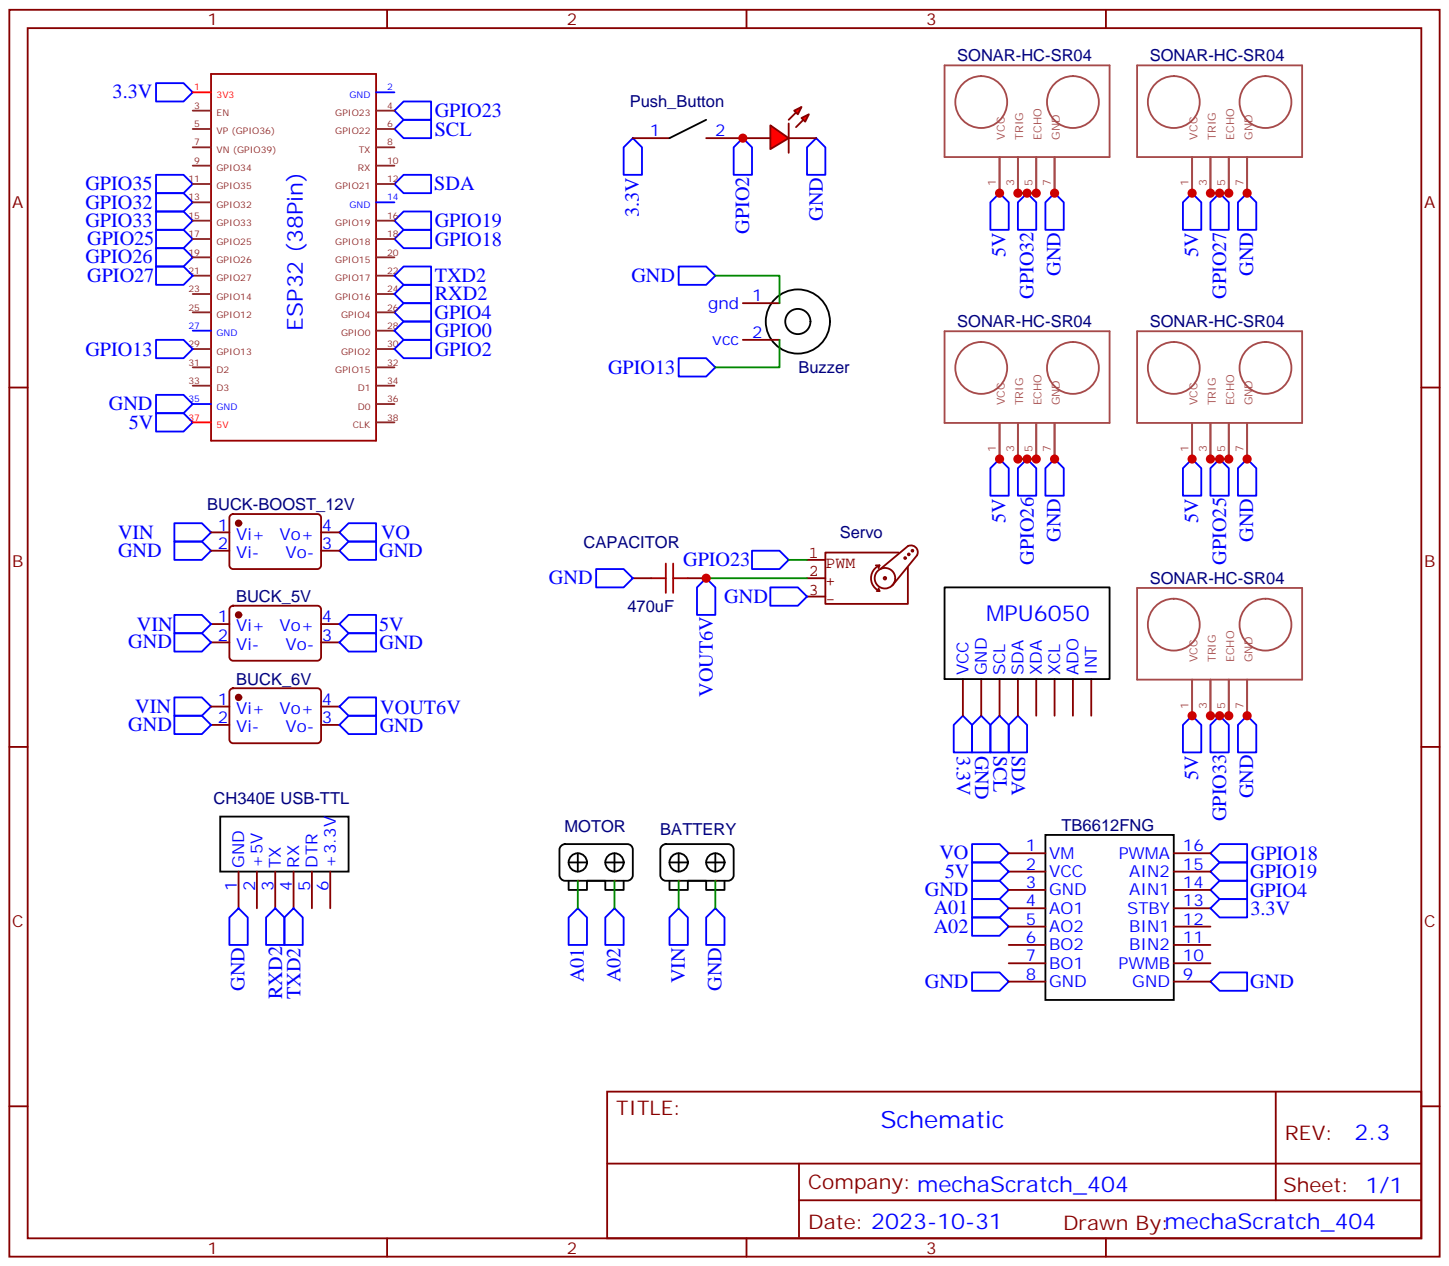
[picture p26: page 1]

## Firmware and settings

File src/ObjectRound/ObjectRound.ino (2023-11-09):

float targetThrottle = 0, throttle = 0;
float targetSteer = 0, steer = 0; // (-)Left, (+)Right
int pwmLimit = 170;
int steerAngle = 20;
int steerMultiplier = 1; // set it to -1 if the steer is reversed
int steerOffset = 7;

float throttleSmoothing = 0.3;
float steerSmoothing = 0.8;

float steerObstacle = 0;
float modAcrossX, modAcrossD;

bool strt = false;
int turnCount = 0;
int totalTurns = 12;
int scndLapTurns = 8; //turns to make the u-turn after
bool justTurned = false;
bool uTurn = true;  // is the robot able to make u-turn? set to false if the last object is green
bool makeUTurn = false; //set to true when the last objet is found and it's red
bool passedLastObj = false; //make the turn after passing the last object
bool firstObjIn = false;
long lastTurnTimer;
int lastTurnTime = 3700;
long uTurnTimer;
int uTurnTime = 4000;
char lstObj7 = 'N';
boolean finished = false;
boolean lastLine = false; //not used
boolean received = false;

long lastGrnTmr = 0;

char fObj = 'N';  //future object, not used
char history[] = {'N', 'N', 'N', 'N', 'N', 'N', 'N', 'N'};  //object history
long objPastTime = 0; //time after the last object

int ignoreD = 7;  //ignore objects if any of the sonar's distance is less than this value
int rDmin[] = {4, 4, 8, 12};    //Minimum distance range for {Side, Angle, Forward, Forward collision}
int rDmax[] = {110, 90, 80, 40}; //Maximum distance range for {Side, Angle, Forward, forward speed}


TaskHandle_t handleSonar;

char objType = 'N'; // N = None, G = Green, R = Red
char lostObj = 'N'; // last passed object
char lastObj = 'N'; // last seen object
long lostTimer = 0;
int lostTime = 200;
float lastObjSteer = -10;

int objDist = 200;
int newObjDist = 200;
int objPos = 0;

int xRange[] = {30, 170};
float rangeAcrossX[] = {0.2, 0.85};
float fRangeAcrossX[] = { -0.6, 0.6};

int dRange[] = {10, 120};
int FDRange[] = {45, 200};
float rangeAcrossD[] = {1, 0.1};
//float fRangeAcrossD[] = {0, 1};

int followD = FDRange[0];
long turnTimer = 0;
long turnTime = 800;
// ---------------------------------- Sonar ---------------------------------- //
#define MAX_DISTANCE 150
int sPins[] = {32, 27, 26, 25, 33};
long dists[] = {0, 0, 0, 0, 0};
long sonarTimer;
// ---------------------------------- Sonar ---------------------------------- //
//                               ---------------                               //
// ---------------------------------- Motor ---------------------------------- //
#define motPWM 18
#define motA 4
#define motB 19
// ---------------------------------- Motor ---------------------------------- //
//                               ---------------                               //
// ---------------------------------- Servo ---------------------------------- //
#include <ESP32Servo.h>

Servo s;
#define servoPin 23
// ---------------------------------- Servo ---------------------------------- //
//                               ---------------                               //
// ----------------------------------- Btn ----------------------------------- //
#define btnPin 2
// ----------------------------------- Btn ----------------------------------- //
//                               ---------------                               //
// ----------------------------------- MPU ----------------------------------- //
#include <MPU6050_tockn.h>
#include <Wire.h>

MPU6050 mpu(Wire);

long lastAngle;
long currentAngle;
// ----------------------------------- MPU ----------------------------------- //
//                               ---------------                               //
// ----------------------------------- COM ----------------------------------- //
#define RXD2 16
#define TXD2 17

long serialTimer;
int key = 0;

int lineAng = 0;
int trackDir = 0; // -1: cw, +1: ccw
// ----------------------------------- COM ----------------------------------- //
//                               ---------------                               //
// -------------------------------- INDICATOR -------------------------------- //
#define RED 15
#define GREEN 15
#define buzz 13

long buzzTimer = 0;
long ledTimer = 0;

long dTmr = 0;
int dt = 1;
void setup() {
  Serial.begin(115200);
  Serial2.begin(115200, SERIAL_8N1, RXD2, TXD2);

  xTaskCreatePinnedToCore(loopB,    "secondJob", 4096,   NULL,      1,        &handleSonar,            0);
  //                     (function, task name,   memory, parameter, priority, task reference,          core)

  Serial2.print("S");
  pinMode(motPWM, OUTPUT);
  pinMode(motA, OUTPUT);
  pinMode(motB, OUTPUT);

  s.attach(servoPin);
  setThrottleSteer(0, 0);

  pinMode(RED, OUTPUT);
  pinMode(GREEN, OUTPUT);
  pinMode(buzz, OUTPUT);


  Wire.begin();
  mpu.begin();
  //mpu.calcGyroOffsets(true);
  Serial.println("Done!\n");
  digitalWrite(buzz, HIGH);
  delay(1000);
  digitalWrite(buzz, LOW);

  pinMode(btnPin, OUTPUT);
  digitalWrite(btnPin, HIGH);
  while (true) {
    if (received) {
      break;
    }
  }
  digitalWrite(btnPin, LOW);

  pinMode(btnPin, INPUT);
  while (digitalRead(btnPin) == 0) { } // wait untill the button is pressed
  delay(700);
  delay(300);
  digitalWrite(GREEN, LOW);

  Serial2.print("S");
  serialTimer = millis();

  getMPU();
  lastAngle = currentAngle;
  if(objType != 'N' && objDist < 30){
    firstObjIn = true;
  }

  pinMode(btnPin, OUTPUT);
  dTmr = millis();
}

void loop() {
  //getMPU

  dt = millis() - dTmr;
  dTmr = millis();
  if (millis() - buzzTimer < 200) {
    digitalWrite(buzz, HIGH);
  } else if (!finished) {
    digitalWrite(buzz, LOW);
  }
  if (millis() - ledTimer < 500 || makeUTurn == 'R') {
    digitalWrite(btnPin, HIGH);
  } else {
    digitalWrite(btnPin, LOW);
  }

  if (!finished && turnCount >= totalTurns) { // if the car finishes three laps
    finished = true;
    lastTurnTimer = millis();
    digitalWrite(buzz, HIGH);
  }
//  if(turnCount == scndLapTurns && objType == 'G' && objDist < 65 && millis() - turnTimer < 2000){
  if(turnCount == scndLapTurns && ((objType == 'G' && objDist < 65 && millis() - turnTimer < 2000) || objType == 'G' && fObj == 'G')){
    uTurn = false;
  }

  if(justTurned && uTurn){
    if(firstObjIn && turnCount == scndLapTurns){
      makeUTurn = true;
      uTurnTimer = millis();
    }
    if(!firstObjIn && turnCount == scndLapTurns+1){
      makeUTurn = true;
      uTurnTimer = millis()-uTurnTime;
    }
    justTurned = false;
  }
  setControls(); // set controls using sonar
  modifyObs();  // modify controls from objects

  if(!makeUTurn) {whenLost();} // after passing an object 

  avoidCollision(rDmin, rDmax);

  //manualTurn();
  targetThrottle = clamp(targetThrottle, -1, 1);
  targetSteer = clamp(targetSteer, -1, 1);

  handleScenarios();
  throttle = lerpF(throttle, targetThrottle, throttleSmoothing);
  steer = lerpF(steer, targetSteer, steerSmoothing);
  throttle = clamp(throttle, -1, 0.6);
  setThrottleSteer(throttle, steer);

  if (makeUTurn && millis() - uTurnTimer > uTurnTime) {
    doUTurn(true);
  }
  
  if (finished && millis() - lastTurnTimer > lastTurnTime) {
    for (float i = 0; i < 0.5; i += 0.2) {
      setThrottleSteer(-i, 0); // stop the car
      delay(1);
    }
    digitalWrite(buzz, LOW);
    setThrottleSteer(0, 0);

    delay(100);
    pinMode(btnPin, OUTPUT);
    pwmLimit = 0;
    while (true) {
      digitalWrite(btnPin, HIGH);
      delay(200);
      digitalWrite(btnPin, LOW);
      delay(200);
    }
  }
}

void loopB(void * param) {
  while (true) {
    getDistanceValues();
    //printDistanceValues();
    delay(10);
    getSerialInfo();
    printSerialInfo();
  }
}

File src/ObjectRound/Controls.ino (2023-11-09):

void onTurn() {
  lostObj = 'N';
  ledTimer = millis();
  lastAngle = currentAngle;
  turnTimer = millis();
  //digitalWrite(buzz, HIGH);
  buzzTimer = millis();
  justTurned = true;
}

void manualTurn() {
  if (millis() - turnTimer < turnTime) {
    if (objType == 'N') {
      targetThrottle = 0.3;
      targetSteer = trackDir * 1;
    }
    else {
      turnTimer -= (turnTime * dt) / 10;
    }
  } else {
    turnTimer = 0;
  }
}

void whenLost() {
  if (lostObj != 'N' && millis() - lostTimer > lostTime) {
    if (millis() - turnTimer < 400) {
      if (trackDir == 1 && lostObj == 'G') {
        return;
      }
      if (trackDir == -1 && lostObj == 'R') {
        return;
      }
    }
    long tmr = millis();
    tmr = millis();
    float _str = 0;
    int tm = (int)clamp(mapFC(lastObjSteer, 0, 800, 0, 1500), 400, 900) + 300;
    while (millis() - tmr > 300 && millis() - tmr < tm && objType == 'N' && turnTimer != 0) {
      if (lostObj == 'R') {
        _str = -0.65;
      } else if (lostObj == 'G') {
        _str = 0.65;
      }
      setThrottleSteer(0.3, _str);
      if (obstacleIn(10, _str)) {
        break;
      }
    }
    /*if (objType == 'N') {
      tmr = millis();
      while (millis() - tmr < (tm * 2) / 3 && objType == 'N') {
        setThrottleSteer(0.4, -_str / 2);
        if (obstacleIn(10, -_str)) {
          break;
        }
      }
      }*/
    lostObj = 'N';
    lastObjSteer = -10;
  }

}

void setControls() {
  float _thr = 1;
  float _steer = 0;

  if (dists[0] < rDmax[0]) {
    float vl = mapFC(dists[0], rDmin[0], rDmax[0], 0.8, 0);
    _steer += vl;
  }
  if (dists[1] < rDmax[1]) {
    float vl = mapFC(dists[1], rDmin[1], rDmax[1], 0.6, 0);
    _steer += vl;
  }

  if (dists[3] < rDmax[1]) {
    float vl = mapFC(dists[3], rDmin[1], rDmax[1], 0.6, 0);
    _steer -= vl;
  }
  if (dists[4] < rDmax[0]) {
    float vl = mapFC(dists[4], rDmin[0], rDmax[0], 0.8, 0);
    _steer -= vl;
  }



  if (dists[2] < rDmax[2]) {
    _thr -= mapFC(dists[2], rDmin[2], rDmax[2], 0.3, 0);
  }
  if (dists[2] < rDmax[3]) {
    _steer *= mapFC(dists[2], rDmin[2], rDmax[3], 2, 1);
  }

  targetThrottle = _thr;
  targetSteer = _steer;
}

void thrFromStr() {
  targetThrottle *= mapFC(abs(targetSteer), 0, 1, 1, 0.5);
}

void modifyObs() {
  for (int i = 0; i < 5; i++) {
    if (dists[i] < ignoreD && i != 2) {
      return;
    }
  }

  if (objType != 'N') {
    targetSteer *= 0.5; //0
    targetThrottle *= 0.6;
    if (objDist > followD) {
      modAcrossD = 1;
      int cPos = scrPos(objType);
      modAcrossX = mapFC(objPos, max(-30, cPos - 100), min(230, cPos + 100), fRangeAcrossX[0], fRangeAcrossX[1]);

    }
    else {
      if (lastObjSteer < 0) {
        lastObjSteer = 0;
      }
      modAcrossD = mapFC(objDist, dRange[0], dRange[1], rangeAcrossD[0], rangeAcrossD[1]);
      if (objType == 'R') {
        modAcrossX = mapFC(objPos, xRange[0], xRange[1], rangeAcrossX[0], rangeAcrossX[1]) * 1.25;
      }
      if (objType == 'G') {
        modAcrossX = -mapFC(objPos, xRange[0], xRange[1], rangeAcrossX[1], rangeAcrossX[0]) * 0.75;
      }
      delay(2);
      lastObjSteer += (modAcrossX * modAcrossD) * targetThrottle * float(dt);
    }
  } else {
    digitalWrite(btnPin, LOW);
  }

  steerObstacle = modAcrossX * modAcrossD;
  targetSteer += steerObstacle;
}

void avoidCollision(int _rDmin[], int _rDmax[]) {
  if (dists[2] < _rDmin[3] /*|| dists[1] < _rDmin[1] || dists[3] < _rDmin[1] || (objDist < 12 && abs(objPos - 100) < 40)*/ ) {
    long _tmr = millis();
    float _str  = 0;
    //float _str  = trackDir;

    if ((objType == 'G' && objDist < 40) || (history[0] == 'R' && objType == 'N')) {
      _str = 0.75;
    }
    else if ((objType == 'R' && objDist < 40) || (history[1] == 'G' && objType == 'N')) {
      _str = -0.75;
    }
    while (millis() - _tmr < 700) {
      setThrottleSteer(-0.6, _str);
      getMPU();
    }
    Serial2.write("<700>");
    setThrottleSteer(0, 0);
    delay(500);
  }
}

void setThrottleSteer(float _thr, float _str) {
  _thr = clamp(_thr, -1, 1);
  _str = clamp(_str, -1, 1);
  delay(2);
  if (_thr == 0) {
    digitalWrite(motA, LOW);
    digitalWrite(motB, LOW);
    digitalWrite(motPWM, LOW);
  }
  else if (_thr > 0) {
    digitalWrite(motA, HIGH);
    digitalWrite(motB, LOW);
    analogWrite(motPWM, int(_thr * pwmLimit));
  }
  else {
    digitalWrite(motA, LOW);
    digitalWrite(motB, HIGH);
    analogWrite(motPWM, int(-_thr * pwmLimit));
  }


  s.write(90 + _str * steerAngle * steerMultiplier + steerOffset);
}

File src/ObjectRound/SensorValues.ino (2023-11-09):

void getDistanceValues() {
  if (millis() - sonarTimer > 15) {
    for (int i = 0; i < 5; i++) {
      dists[i] = getDistS(sPins[i]);
    }
  }
}

void printDistanceValues() {
  Serial.print("Sonar Values: ");
  for (int i = 0; i < 5; i++) {
    Serial.print(dists[i]);
    Serial.print(" - ");
  }
  Serial.println(" | ");
}

int getDistS(int te) {
  pinMode(te, OUTPUT);

  digitalWrite(te, LOW);
  delayMicroseconds(2);
  digitalWrite(te, HIGH);
  delayMicroseconds(10);
  digitalWrite(te, LOW);

  pinMode(te, INPUT);

  long dur = pulseIn(te, HIGH, MAX_DISTANCE * 60);
  int dst = dur / 58.8;
  if (dst <= 1) dst = MAX_DISTANCE;
  return (dst);
}


void getSerialInfo() {
  if (millis() - serialTimer > 15) {
    Serial2.print("D");
    serialTimer = millis();
  }

  char thisObj = 'N';
  bool newObj = false;
  while (Serial2.available()) {
    int val = Serial2.read();
    received = true;
    if (val < 50) {
      key = val;
    }

    else {
      switch (key) {
        case 2:
          if (val == 51) {
            fObj = 'R';
            
          }
          if (val == 52) {
            fObj = 'N';
          }
          if (val == 53) {
            fObj = 'G';
          }
          break;
        case 5:
          if (val == 51) {
            thisObj = 'R';
            objPastTime = millis();
          }
          if (val == 52) {
            thisObj = 'N';
          }
          if (val == 53) {
            thisObj = 'G';
            objPastTime = millis();
          }
          if (objType != thisObj) {
            if (thisObj == 'N') {
              if (objType == 'R') {
                lostObj = 'R';
                lostTimer = millis();
              } else if (objType == 'G') {
                lostObj = 'G';
                lostTimer = millis();
              }
            } else {
              newObj = true;
              lastObjSteer = -10;
            }
            objType = thisObj;
          }
          else if (objType == thisObj and objType != 'N') {
            lostObj = 'N';
          }
          break;
        case 6:
          objPos = val - 50;
          break;
        case 7:
          newObjDist = val - 50;
          break;
        case 8:
          if (val - 50 != turnCount) {
            onTurn();
          }

          turnCount = val - 50;
          break;

        case 10:
          trackDir = val - 150;
          break;
        case 11:
          if (val > 55) {
            lastLine = true;
          }
          else {
            lastLine = false;
          }
          break;
        case 12:
          if (val == 51) {
            lstObj7 = 'R';
          }
          break;
      }
    }
  }
  if (newObj || newObjDist > objDist + 15) {
    addHistory(thisObj);
    lostTimer = millis();
    if (objDist < followD) {
      lastObj = thisObj;
    }
  }
  objDist = newObjDist;
}

bool obstacleIn(int dist, float _str) {
  if(_str > 2){
    for(int i = 1; i < 5; i++){
      if(dists[i] < dist){
        return true;
      }
    }
  }
  if (_str < -0.2) {
    if (dists[0] < dist || dists[1] < dist) {
      return true;
    }
  }
  if (_str > 0.2) {
    if (dists[2] < dist || dists[3] < dist) {
      return true;
    }
  }
  for (int i = 1; i < 4; i++) {
    if (dists[i] < dist) {
      return true;
    }
  }
  return false;
}

void printSerialInfo() {
  Serial.print("turnCount: ");
  Serial.print(trackDir);
  Serial.print(".");
  Serial.print(turnCount);
  Serial.print(" - Obj: ");
  Serial.print(String(history[0]) + String(objType) + String(fObj));
  Serial.print(" | ");
  Serial.print(objPos);
  Serial.print(" | ");
  Serial.print(objDist);
  Serial.print("||Mod");
  Serial.print(modAcrossX);
  Serial.print(":");
  Serial.print(modAcrossD);
  Serial.print(":");
  Serial.println(steerObstacle);
}

void sendDelay(int del) {
  Serial1.print("<" + String(del) + ">");
}
void getMPU() {
  mpu.update();
  currentAngle = mpu.getGyroAngleY();
}


void addHistory(char ob) {
  if (ob != 'N') {
    for (int i = 7; i > 0; i--) {
      history[i] = history[i - 1];
    }
    history[0] = ob;
  }
}

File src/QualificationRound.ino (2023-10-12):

float throttle = 0;
float steer = 0;
float throttleMult = 1;
int steerAngle = 30;
int steerMultiplier = 1; // set it to -1 if the steer is reversed
int steerOffset = 5;

float throttleSmoothing = 0.6;
float steerSmoothing = 0.5;

int turnCount = 0;
int totalTurns = 12;
long lastTurnTimer;
int lastTurnTime = 6000;
boolean finished = false;

long rDmin[] = {2, 2, 2};    //Minimum distance range for {Side, Angle, Forward}
long rDmax[] = {60, 70, 60}; //Maximum distance range for {Side, Angle, Forward}

TaskHandle_t handleSonar;

// ---------------------------------- Sonar ---------------------------------- //
#include <NewPing.h>

#define MAX_DISTANCE 120

NewPing sonars[] = {
  NewPing(26, 26, MAX_DISTANCE),
  NewPing(27, 27, MAX_DISTANCE),
  NewPing(32, 32, MAX_DISTANCE),
  NewPing(33, 33, MAX_DISTANCE),
  NewPing(25, 25, MAX_DISTANCE)
};

long dists[] = {0, 0, 0, 0, 0};
// ---------------------------------- Sonar ---------------------------------- //
//                               ---------------                               //
// ---------------------------------- Motor ---------------------------------- //
#define motPWM 4
#define motA 17
#define motB 16
// ---------------------------------- Motor ---------------------------------- //
//                               ---------------                               //
// ---------------------------------- Servo ---------------------------------- //
#include <ESP32Servo.h>

Servo s;
#define servoPin 18
// ---------------------------------- Servo ---------------------------------- //
//                               ---------------                               //
// ----------------------------------- Btn ----------------------------------- //
#define btnPin 19
// ----------------------------------- Btn ----------------------------------- //
//                               ---------------                               //
// ----------------------------------- MPU ----------------------------------- //
#include "Wire.h"
#include <MPU6050_light.h>

MPU6050 mpu(Wire);
long lastAngle;
long currentAngle;
// ----------------------------------- MPU ----------------------------------- //
//                               ---------------                               //
// -------------------------------- INDICATOR -------------------------------- //
#define RED 15
#define GREEN 2

void setup() {
  Serial.begin(115200);

  xTaskCreatePinnedToCore(loopB,    "secondJob", 4096,   NULL,      1,        &handleSonar,            0);
  //                     (function, task name,   memory, parameter, priority, task reference,          core)

  pinMode(motPWM, OUTPUT);
  pinMode(motA, OUTPUT);
  pinMode(motB, OUTPUT);

  s.attach(servoPin);
  setThrottleSteer(0, 0);

  pinMode(btnPin, INPUT);

  pinMode(RED, OUTPUT);
  pinMode(GREEN, OUTPUT);

  //Wire.begin();
  //byte status = mpu.begin();
  Serial.print(F("MPU6050 status: "));
  //Serial.println(status);
  //while(status!=0){ }
  digitalWrite(GREEN, HIGH);

  Serial.println(F("Calculating offsets"));
  // mpu.upsideDownMounting = true;
  //mpu.calcOffsets();
  Serial.println("Done!\n");
  while (digitalRead(btnPin) == 0) { } // wait untill the button is pressed
  delay(1000);
  digitalWrite(GREEN, LOW);

  //currentAngle = mpu.getAngleZ();
  lastAngle = currentAngle;
}

void loop() {
  //mpu.update();
  //currentAngle = mpu.getAngleZ();
  if (abs(lastAngle - currentAngle) > 90) {
    turnCount ++;
    lastAngle = currentAngle;
  }
  if (!finished && turnCount >= totalTurns) { // if the car finishes three laps
    finished = true;
    lastTurnTimer = millis();
  }

  setControls();
  throttle = clamp(throttle, 0, 1);
  steer = clamp(steer, -1, 1);

  thrFromStr();
  setThrottleSteer(throttle, steer);

  if (finished && millis() - lastTurnTimer > lastTurnTime) { // Run another <lastTurnTime> milliseconds
    setThrottleSteer(0, 0); // stop the car
    digitalWrite(GREEN, HIGH);
    while (digitalRead(btnPin) == 0) { } // wait untill the button is pressed
    delay(1000);

    currentAngle = mpu.getAngleZ();
    lastAngle = currentAngle;
    turnCount = 0;
    finished = false;
  }
}

void loopB(void * param) {
  while (true) {
    getDistanceValues();
  }
}


void setControls() {
  float _thr = 1;
  float _steer = 0;

  if (dists[0] < rDmax[0]) {
    float vl = mapFC(dists[0], rDmin[0], rDmax[0], 0.4, 0);
    _steer -= vl * vl;
  }
  if (dists[1] < rDmax[1]) {
    float vl = mapFC(dists[1], rDmin[1], rDmax[1], 0.6, 0);
    _steer -= vl * vl;
  }

  if (dists[3] < rDmax[1]) {
    float vl = mapFC(dists[3], rDmin[1], rDmax[1], 0.6, 0);
    _steer += vl * vl;
  }
  if (dists[4] < rDmax[0]) {
    float vl = mapFC(dists[4], rDmin[0], rDmax[0], 0.4, 0);
    _steer += vl * vl;
  }


  if (dists[2] < rDmax[2]) {
    _thr -= mapFC(dists[2], rDmin[2], rDmax[2], 1, 0);
    _steer *= mapFC(dists[2], rDmin[2], rDmax[2]*3, 3.5, 1);
  }
  throttle = lerpF(throttle, _thr, throttleSmoothing);
  steer = lerpF(steer, _steer, steerSmoothing);
}

void thrFromStr(){
  throttle *= mapFC(abs(steer), 0, 1, 1, 0.6);
}

void getDistanceValues() {
  long sonarTimer = millis();
  Serial.print("Sonar Values: ");
  for (int i = 0; i < 5; i++) {
    dists[i] = sonars[i].ping_cm();
    if (dists[i] == 0) {
      dists[i] = MAX_DISTANCE;
    }
    Serial.print(dists[i]);
    Serial.print(" - ");
  }
  Serial.println(" | ");
  delay(10);
  while (millis() - sonarTimer < 15) { } // ensures a 30ms delay between pings per sonar
}

void setThrottleSteer(float _thr, float _str) {
  _thr *= throttleMult;
  Serial.println(int(_thr * 255));
  if (_thr == 0) {
    digitalWrite(motA, LOW);
    digitalWrite(motB, LOW);
  }
  else if (_thr > 0) {
    digitalWrite(motA, HIGH);
    digitalWrite(motB, LOW);
    analogWrite(motPWM, int(_thr * 255));
  }
  else {
    digitalWrite(motA, LOW);
    digitalWrite(motB, HIGH);
    analogWrite(motPWM, int(-_thr * 255));
  }

  s.write(90 + _str * steerAngle * steerMultiplier + steerOffset);
}

float mapF(float x, float in_min, float in_max, float out_min, float out_max) {
  return (x - in_min) * (out_max - out_min) / (in_max - in_min) + out_min;
}

float mapFC(float x, float in_min, float in_max, float out_min, float out_max) {
  return clamp( mapF(x, in_min, in_max, out_min, out_max), out_min, out_max);
}

float clamp(float val, float mini, float maxi) {
  if (val < mini) {
    return mini;
  }
  if (val > maxi) {
    return maxi;
  }
  return val;
}

float lerpF(float a, float b, float t)
{
  return a + t * (b - a);
}

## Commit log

2023-10-11 3D Models for printing
2023-10-11 Add Steering Mechanism
2023-10-17 Installing Jetson nano
2023-10-28 Control servo from serial monitor
2023-10-31 Circuitry Update
2023-10-31 Circuit Update
2023-10-31 Diff GearBox
    [BackWheel (2x) (Mid).stl, GearBox_Bottom (1x) (Weak).stl, GearBox_Top (1x) (Weak).stl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]
2023-11-07 assembly steps simplified
